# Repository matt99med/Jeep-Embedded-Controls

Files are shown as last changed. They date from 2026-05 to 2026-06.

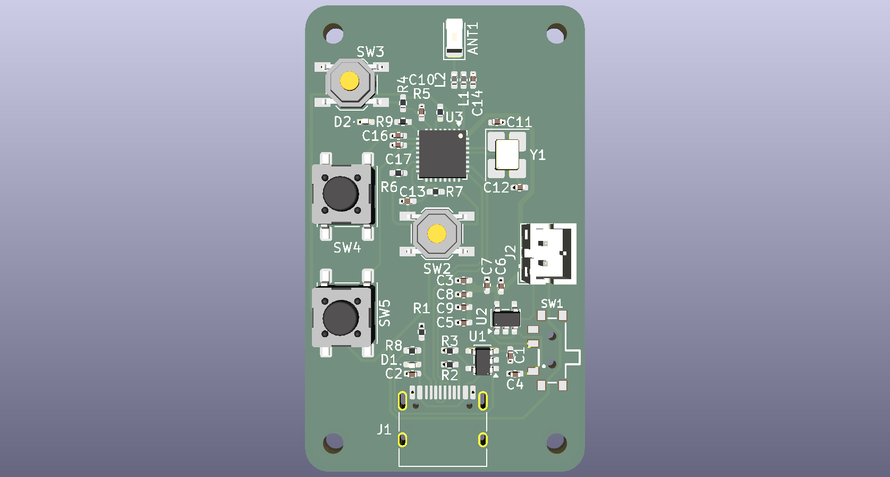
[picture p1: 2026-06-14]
images/JeepKeyfob_3D_Top.png

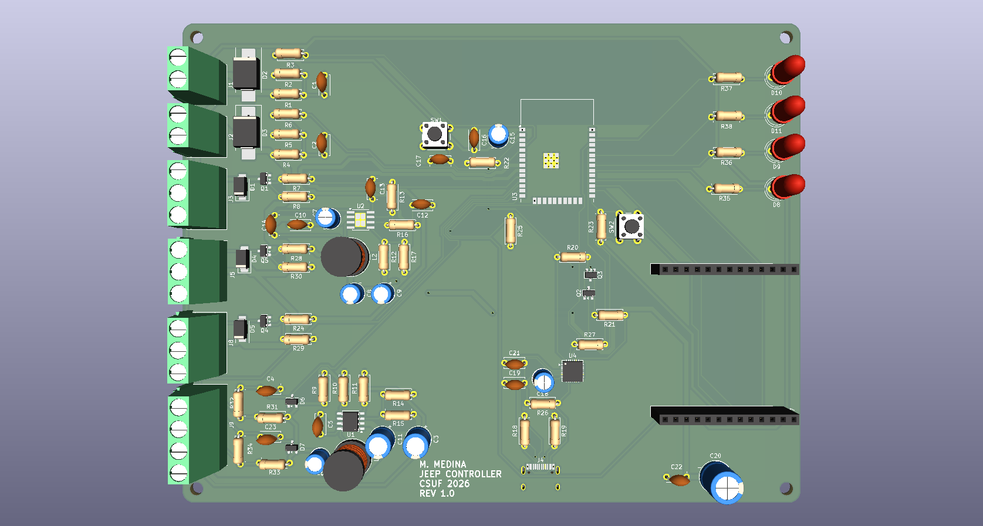
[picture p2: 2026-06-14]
images/JeepController_3D_Top.png

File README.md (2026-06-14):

# Jeep Embedded Controls

A custom embedded security and control system for a 1995 Jeep Wrangler, built as a
personal project to demonstrate full-stack embedded systems development across firmware,
hardware, PCB design, power electronics, and mobile applications.

## Project Overview

This system provides remote control, alarm/immobilization, and real-time GPS tracking
for a 1995 Jeep Wrangler using two custom-designed PCBs, 3D printed enclosures, and a
companion web app. A keyfob and a main controller communicate wirelessly via ESP-NOW,
with 4G LTE cellular for remote GPS tracking accessible from any device.

The system is designed around a **battery-backed, low-power security architecture**: the
controller runs from its own auxiliary battery so it keeps tracking and alarming even if
the vehicle's main battery is disconnected — the exact scenario a theft involves — while
never drawing the vehicle battery down when parked.

## Demo

> Live GPS tracker web app: [Jeep Tracker](https://matt99med.github.io/Jeep-Embedded-Controls/)

## Features

- Remote kill switch (immobilizer) via custom ESP-NOW keyfob
- **Hidden manual bypass switch** — fail-safe so a controller fault never strands the vehicle
- Hood and shock sensor triggered siren with automatic arming
- Remote arm/disarm via keyfob with LED status feedback
- Real-time GPS tracking via 4G LTE cellular (SIM7600G-H)
- Web app for live location tracking via MQTT over HiveMQ Cloud
- **Auxiliary backup battery** — system survives main-battery disconnect
- **Vehicle-sensing charge control** — aux battery charges only while the alternator runs,
  so the vehicle battery is never drained while parked (months of standby)
- **Deep-sleep architecture** — wakes on hood/shock/timer events; tens of µA when parked
- Hardware low-voltage disconnect protecting the aux battery from over-discharge
- LiPo battery powered keyfob with USB-C charging

## Hardware

### Main Controller

- **ESP32-WROOM-32E** module (240MHz dual-core, Wi-Fi, BT)
- **CP2102N** USB-to-UART bridge with auto-reset programming circuit (USB-C)
- **SIM7600G-H** 4G LTE + GPS (Waveshare breakout, socketed)
- **Auxiliary battery system:** 12V sealed AGM battery
- **Vehicle-sensing charge relay:** connects vehicle 12V to aux battery only when the
  alternator is running (firmware-controlled, AO3400A driver, off-board relay)
- **Power rails:**
  - LM5164-Q1 wide-Vin synchronous buck (battery -> 3.3V, ~10uA quiescent)
  - MP2307DN buck (battery -> 3.8V for SIM7600, gated by GPIO for sleep)
  - Hardware UVLO low-voltage disconnect on the 3.3V buck
- Relay/fuse box for kill switch + siren (off-board high current)
- BAT54S input clamps + RC filtering on hood/shock sensor inputs
- SMCJ33A TVS protection on 12V inputs
- 4 firmware-controlled status LEDs (system / cellular / armed / fault)
- Custom 2-layer KiCad PCB, 154.5 x 120 mm
- Custom Fusion 360 enclosure (in progress)

### Keyfob

- **ESP32-C3FH4X** (bare QFN32, 160MHz RISC-V, in-package 4MB flash)
- **Johanson 2450AT18A100E-AEC** chip antenna with L-C-L matching network
- 40MHz crystal (NX3225GD-40M)
- MCP73831 LiPo charger IC
- 3.7V LiPo battery
- USB-C charging + native USB programming (GPIO18/19)
- AP2112K-3.3 LDO
- Tactile buttons: Lock, Unlock + BOOT/RESET
- Status LEDs: charge + connection
- Slide power switch
- Custom 2-layer KiCad PCB, 30 x 50 mm
- Custom Fusion 360 enclosure (in progress)

## Tech Stack

| Category | Technology |
| --- | --- |
| Firmware | ESP-IDF v6.0 (C) |
| RTOS | FreeRTOS |
| Wireless | ESP-NOW (keyfob <-> controller) |
| Cellular | SIM7600G-H AT commands over UART2 |
| IoT Protocol | MQTT over TLS (HiveMQ Cloud) |
| PCB Design | KiCad 10.0 |
| 3D Modeling | Autodesk Fusion 360 |
| Web App | HTML/CSS/JavaScript + Google Maps API |
| Version Control | Git/GitHub |
| PCB Fabrication | JLCPCB (assembled) |

## System Architecture

```
[Keyfob ESP32-C3] <--ESP-NOW 2.4GHz--> [Main ESP32 Controller]
[Lock/Unlock]                            [Kill Switch / Siren]
                                         [Hood + Shock Sensors]
                                         [Aux Battery + Charge Control]
                                         [Hidden Bypass Switch]
                                                 |
                                         [SIM7600G-H Module]
                                                 |
                                      [Hologram IoT SIM / 4G LTE]
                                                 |
                                        [HiveMQ MQTT Broker]
                                                 |
                                     [Web App / iPhone / Any Device]
```

## Power Architecture

```
[Vehicle 12V] --fused--> [Charge Relay] --(only when alternator running)--> [Aux 12V Battery]
                              ^                                                    |
                       [GPIO sense/control]                                        |
                                                                                   v
                                                          +------------------------+
                                                          |                        |
                                                  [LM5164 Buck]            [MP2307 Buck]
                                                   3.3V (always-on,         3.8V (gated,
                                                   UVLO protected)          SIM7600)
                                                          |                        |
                                                  [ESP32 + logic]          [SIM7600G-H]
```

Key property: when parked, the vehicle battery and the aux battery are physically
disconnected. The controller draws only from the aux battery, so the vehicle always
starts no matter how long it sits.

## Firmware Architecture

The main controller firmware is built around a **tiered low-power state machine** rather
than always-on tasks, to achieve months of parked standby on the auxiliary battery.

### Operating Model

- **Deep sleep** is the default parked state — modem off, CPU halted, only RTC wake
  sources armed. Draw is in the tens of uA.
- **Wake sources:** hood sensor (RTC GPIO), shock sensor (RTC GPIO), or a wake timer for
  scheduled MQTT check-ins. The check-in interval shortens automatically when armed.
- **Active window:** after any activity the controller stays in *light sleep* so the
  radio remains listenable, giving near-instant ESP-NOW lock/unlock response. After an
  idle timeout it drops back to deep sleep.
- On every wake the controller reads vehicle + battery voltage, runs charge control, and
  — if armed and triggered — fires the siren, immobilizes, and pushes an alert + GPS
  burst over cellular.

### Kill Relay Logic (fail-safe)

The kill relay is **energized-to-run**: driving the coil HIGH closes the starter circuit
(vehicle can start); LOW immobilizes. A dead controller, dead battery, or cut wire
therefore fails *immobilized*, and the hidden mechanical bypass switch is the recovery
path. The bypass is intentionally not wired to the PCB.

### Charge Control

Firmware closes the charge relay above 13.2 V on the vehicle-sense line (alternator
running) and opens it below 12.8 V, with hysteresis to avoid chatter. The relay coil is
fed from the vehicle side, so charging is physically impossible when the engine is off
regardless of firmware state.

### Source Layout

```
main_controller/main/
├── main.c            # wake-reason dispatch, tiered sleep state machine
├── config.h          # pin map, thresholds, ESP-NOW protocol
├── system_state.h    # shared state + arm/alarm/charge API
├── gpio_handler.c    # ADC sensing, relay control, arm/alarm, charge logic
├── espnow_handler.c  # keyfob command receiver
└── sim7600.c         # modem power sequencing, GPS, MQTT

keyfob/main/
├── main.c            # deep-sleep wake-on-button, send, LED ack, sleep
├── config.h          # pin map + ESP-NOW protocol
├── espnow_keyfob.c   # one-shot ESP-NOW transmit
└── espnow_keyfob.h
```

### ESP-NOW Message Protocol

| Command | Value | Action |
| --- | ----- | --- |
| CMD_LOCK | 0x01  | Arm siren + immobilize (kill LOW)  |
| CMD_UNLOCK  | 0x02  | Disarm + allow run (kill HIGH) |

### MQTT Topics

| Topic | Direction | Payload |
| --- | --- | --- |
| jeep/gps/request | App -> ESP32 | "request" |
| jeep/gps/data | ESP32 -> App | {"lat":xx.xxx,"lon":xx.xxx} |
| jeep/status | ESP32 -> App | "armed" or "disarmed" |
| jeep/alert | ESP32 -> App | power-cut / tamper event |

> Broker credentials and APN are provided via NVS / `idf.py menuconfig`, not committed to
> source.

## PCB Design

### Keyfob PCB

- 2-layer board, 30 x 50 mm
- All 0402 passives, JLCPCB assembled
- Bare ESP32-C3FH4X with Johanson chip antenna + matching network
- GND copper pour on B.Cu with via stitching
- M2 mounting holes
- USB-C edge connector for charging + programming
- **Status: ordered from JLCPCB (assembled) — awaiting delivery**

### Main Controller PCB

- 2-layer board, 154.5 x 120 mm
- Automotive environment rated design
- Bare ESP32-WROOM-32E + CP2102N programming
- Dual switching power supplies (LM5164 + MP2307)
- Aux battery charge management + UVLO
- Screw-terminal field wiring, socketed SIM7600 carrier
- GND copper pour on B.Cu with via stitching
- M3 mounting holes in all 4 corners
- **Status: ordered from JLCPCB (assembled) — awaiting delivery**

## Status

- [x] Hardware redesign complete (KiCad schematics — both boards, bare-chip)
- [x] Battery-backed power architecture with vehicle-sensing charge control
- [x] Firmware rework for deep-sleep / charge-control architecture
- [x] Keyfob PCB ordered (JLCPCB assembled)
- [x] Main controller PCB ordered (JLCPCB assembled)
- [ ] PCB bring-up and board-level testing
- [ ] SIM7600 MQTT/cellular integration (broker connect + report cycle)
- [ ] 3D printed enclosures (Fusion 360 — in progress)
- [ ] Hidden bypass switch installation
- [ ] System integration and testing
- [ ] Final installation in 1995 Jeep Wrangler

## Author

**Matthew Medina**

California State University Fullerton — BS/MS Computer Engineering

GitHub: [matt99med](https://github.com/matt99med)

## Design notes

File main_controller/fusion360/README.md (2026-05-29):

# Fusion 360 Enclosures

3D printed enclosures for the Jeep Controller system.

## Designs in progress
- Main controller engine bay enclosure
- Keyfob enclosure
- Off-road light switch panel (radio delete)

STL files will be added here when designs are complete.

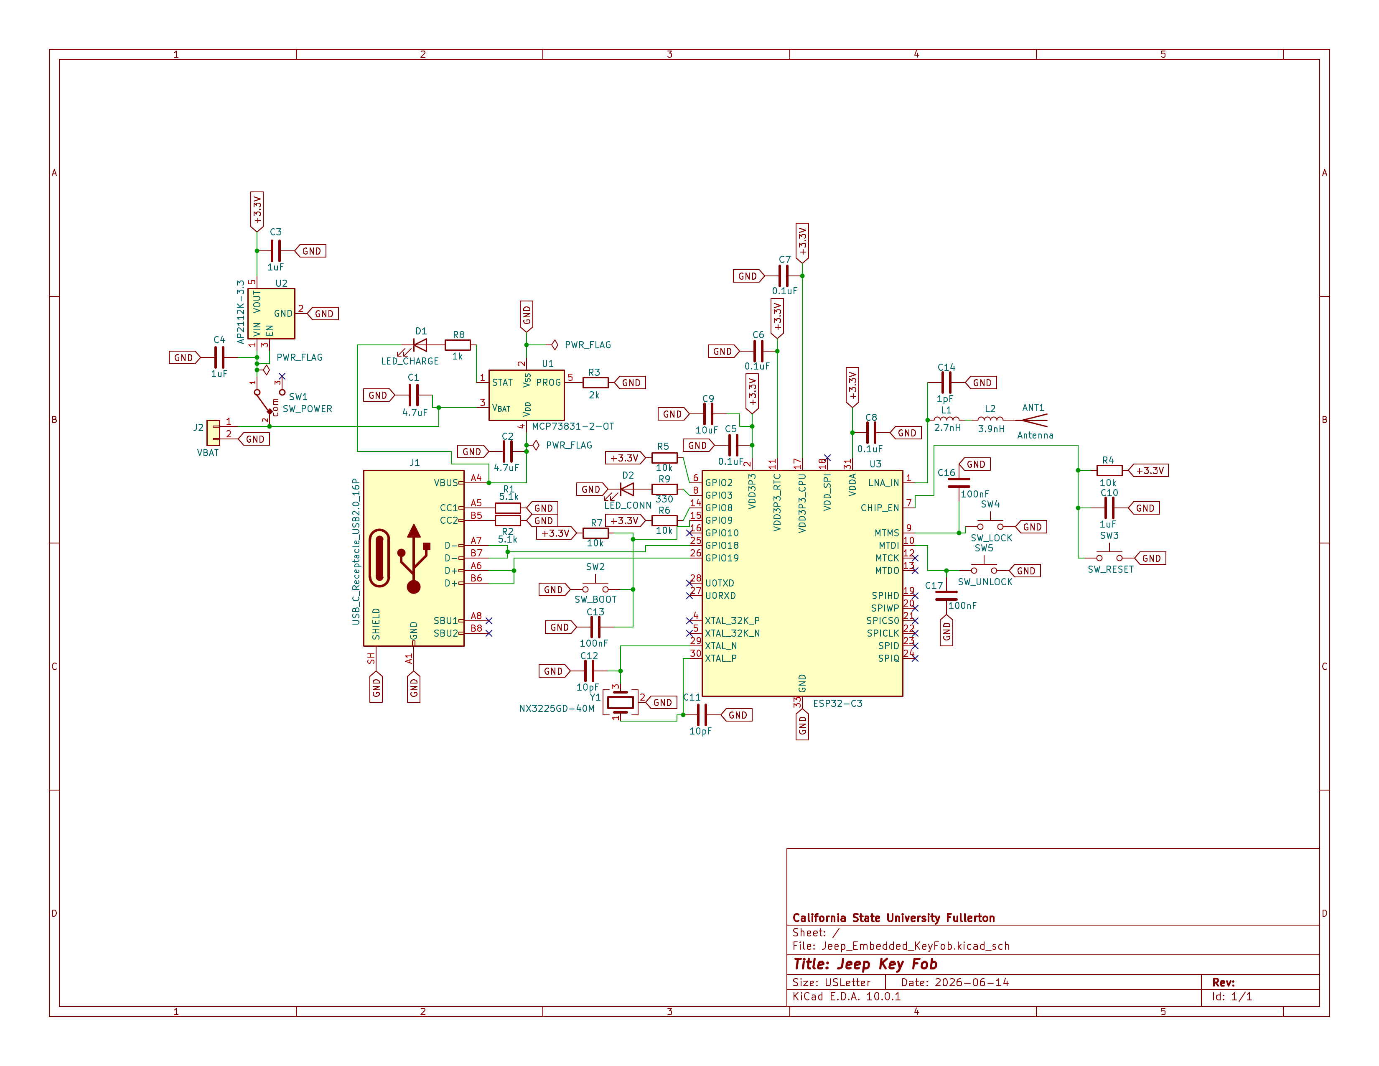
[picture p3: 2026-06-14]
schematics/Jeep_KeyFob.png

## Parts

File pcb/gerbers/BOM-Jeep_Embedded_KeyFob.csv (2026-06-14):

Comment | Designator | Footprint | LCSC | Quantity
0.1uF | C5,C6,C7,C8 | C_0402_1005Metric_Pad0.74x0.62mm_HandSolder | C141382 | 4
100nF | C13,C16,C17 | C_0402_1005Metric_Pad0.74x0.62mm_HandSolder | C1525 | 3
10k | R4,R5,R6,R7 | R_0402_1005Metric_Pad0.72x0.64mm_HandSolder | C11616 | 4
10pF | C11,C12 | C_0402_1005Metric_Pad0.74x0.62mm_HandSolder | C32949 | 2
10uF | C9 | C_0402_1005Metric_Pad0.74x0.62mm_HandSolder | C15525 | 1
1k | R8 | R_0402_1005Metric_Pad0.72x0.64mm_HandSolder | C11702 | 1
1pF | C14 | C_0402_1005Metric_Pad0.74x0.62mm_HandSolder | C1550 | 1
1uF | C10,C3,C4 | C_0402_1005Metric_Pad0.74x0.62mm_HandSolder | C52923 | 3
2.7nH | L1 | L_0402_1005Metric_Pad0.77x0.64mm_HandSolder | C27123 | 1
2k | R3 | R_0402_1005Metric_Pad0.72x0.64mm_HandSolder | C4109 | 1
3.9nH | L2 | L_0402_1005Metric_Pad0.77x0.64mm_HandSolder | C14033 | 1
330 | R9 | R_0402_1005Metric_Pad0.72x0.64mm_HandSolder | C25104 | 1
4.7uF | C1,C2 | C_0402_1005Metric_Pad0.74x0.62mm_HandSolder | C23733 | 2
5.1k | R1,R2 | R_0402_1005Metric_Pad0.72x0.64mm_HandSolder | C25905 | 2
AP2112K-3.3 | U2 | SOT-23-5 | C51118 | 1
Antenna | ANT1 | Johanson_2450AT18x100 | C89334 | 1
ESP32-C3 | U3 | QFN-32-1EP_5x5mm_P0.5mm_EP3.7x3.7mm | C2858491 | 1
LED_CHARGE | D1 | LED_0402_1005Metric_Pad0.77x0.64mm_HandSolder | C71911 | 1
LED_CONN | D2 | LED_0402_1005Metric_Pad0.77x0.64mm_HandSolder | C74338 | 1
MCP73831-2-OT | U1 | SOT-23-5 | C424093 | 1
NX3225GD-40M | Y1 | Crystal_SMD_3225-4Pin_3.2x2.5mm_HandSoldering | C9010 | 1
SW_BOOT | SW2 | SW_SPST_TL3342 | C19779067 | 1
SW_LOCK | SW4 | SW_SPST_PTS645Sx43SMTR92 | C19779067 | 1
SW_POWER | SW1 | 450404015514 | C97433 | 1
SW_RESET | SW3 | SW_SPST_TL3342 | C19779067 | 1
SW_UNLOCK | SW5 | SW_SPST_PTS645Sx43SMTR92 | C19779067 | 1
USB_C_Receptacle_USB2.0_16P | J1 | USB_C_Receptacle_HRO_TYPE-C-31-M-12 | C393939 | 1
VBAT | J2 | JST_PH_B2B-PH-K_1x02_P2.00mm_Vertical | C131337 | 1

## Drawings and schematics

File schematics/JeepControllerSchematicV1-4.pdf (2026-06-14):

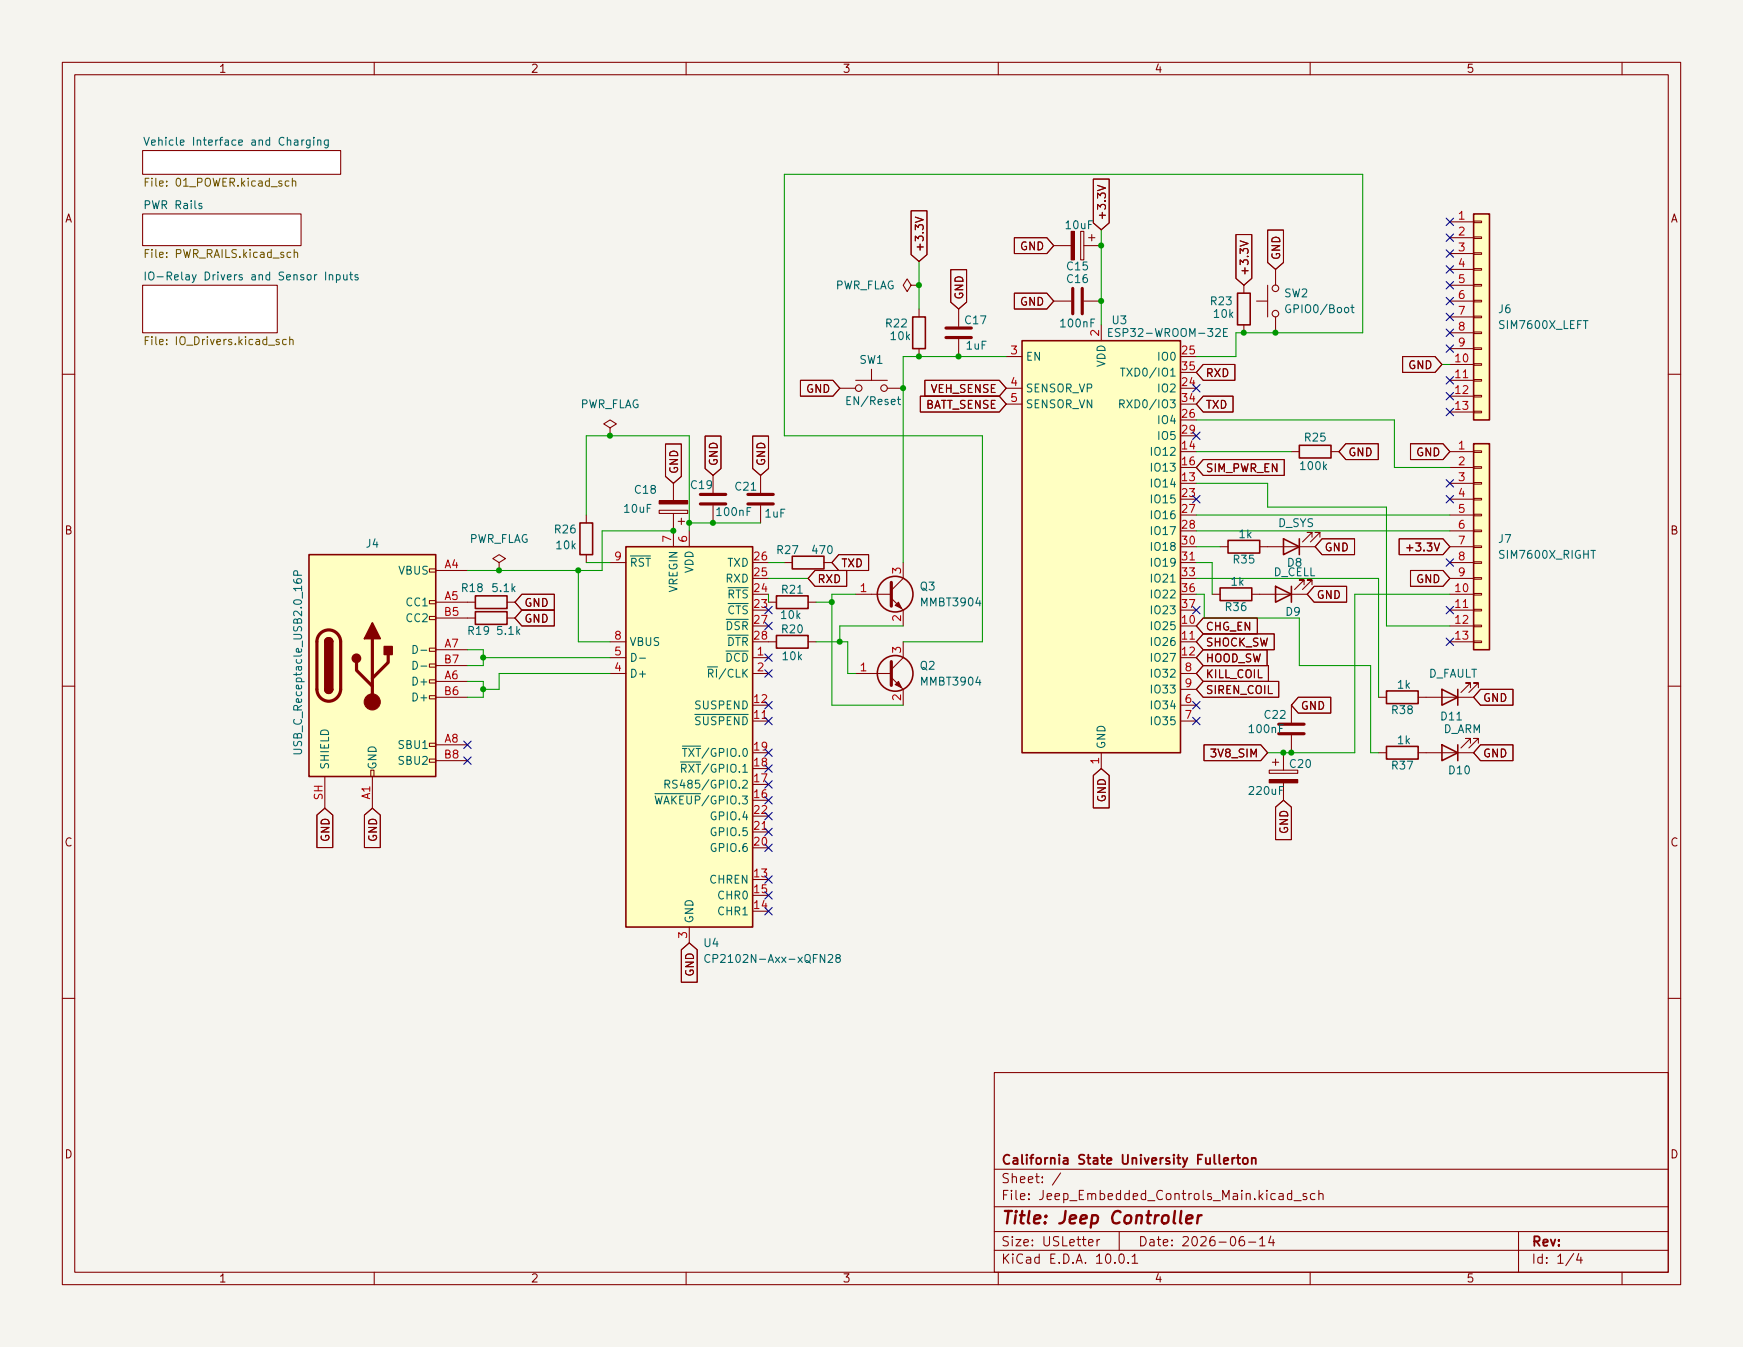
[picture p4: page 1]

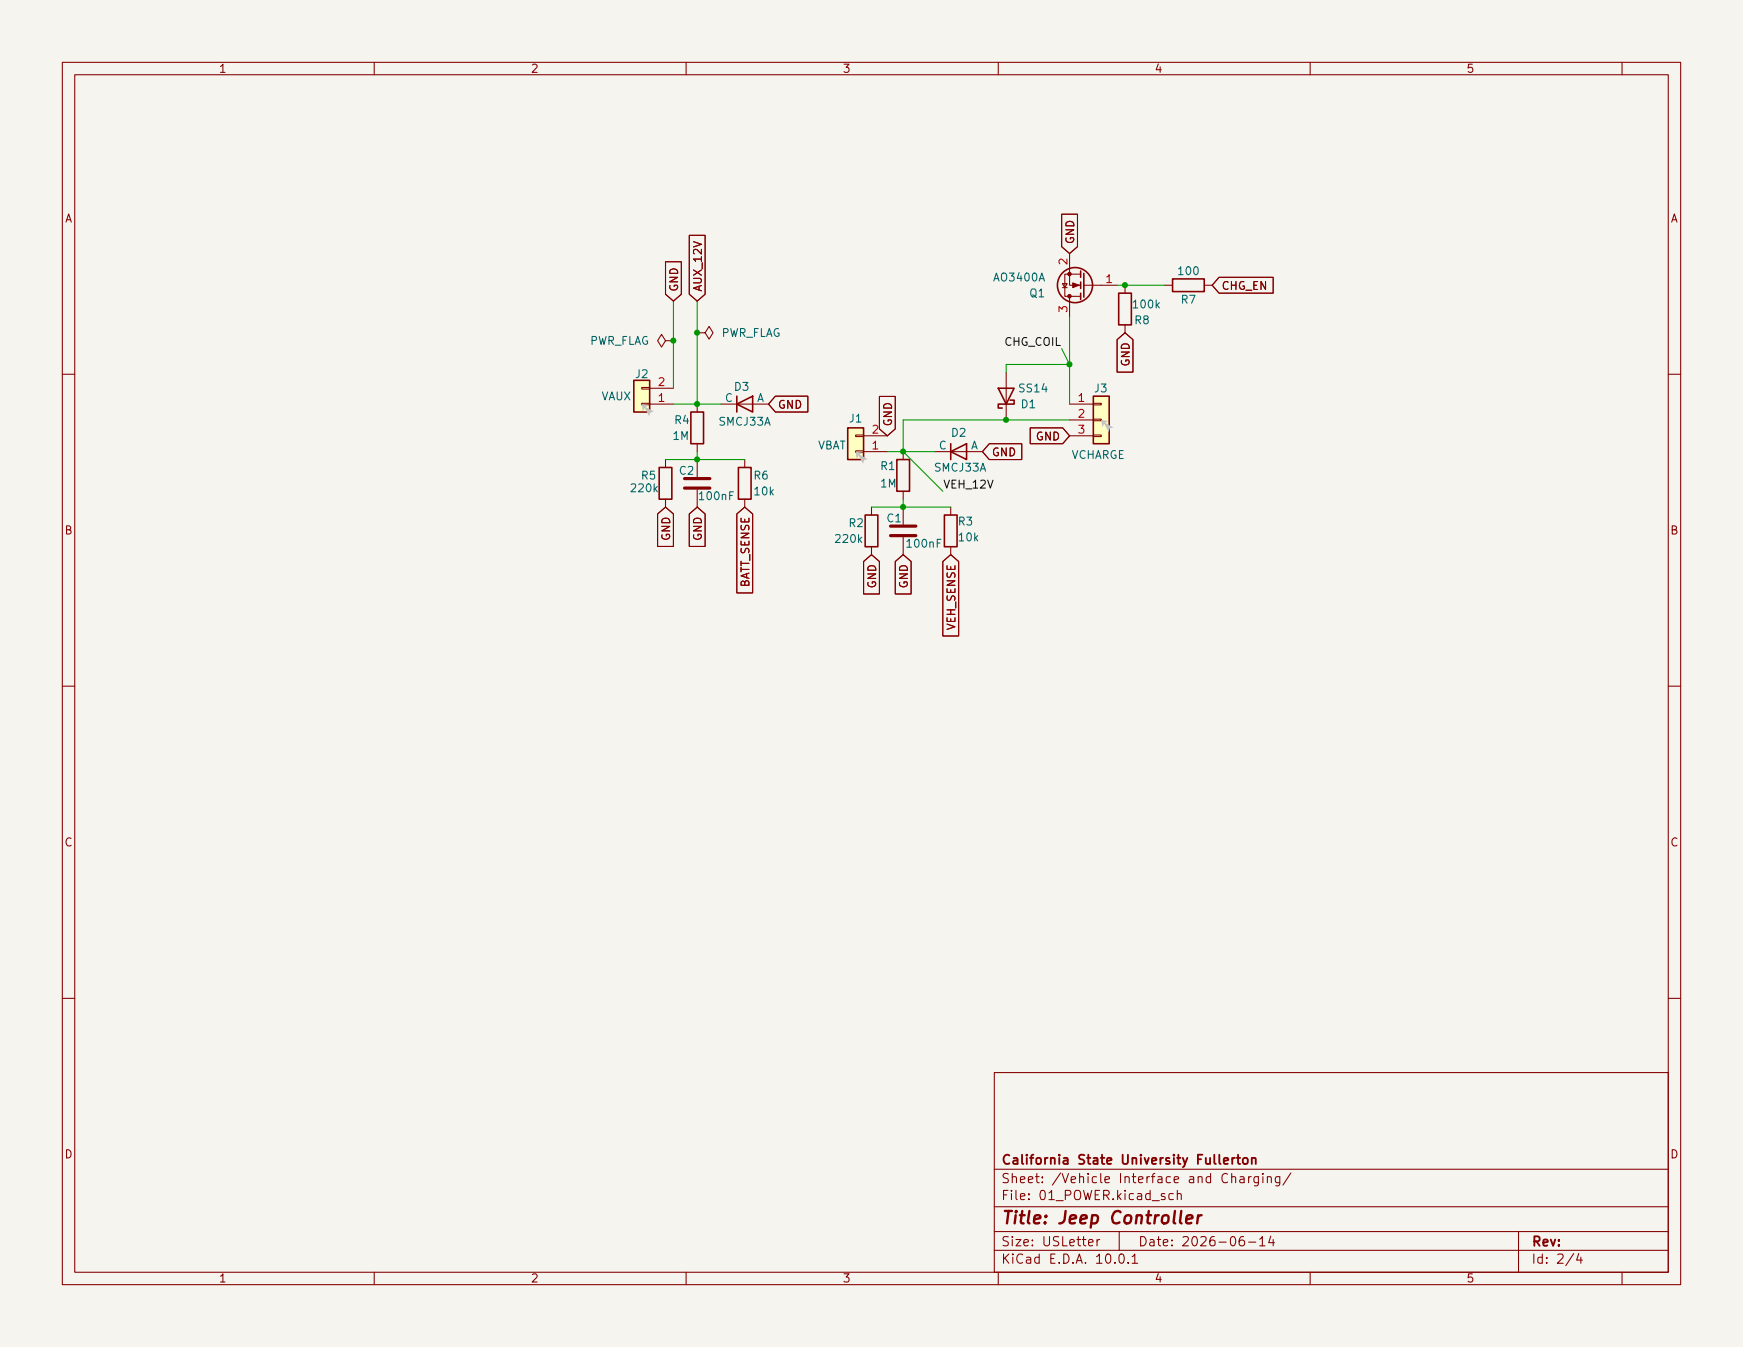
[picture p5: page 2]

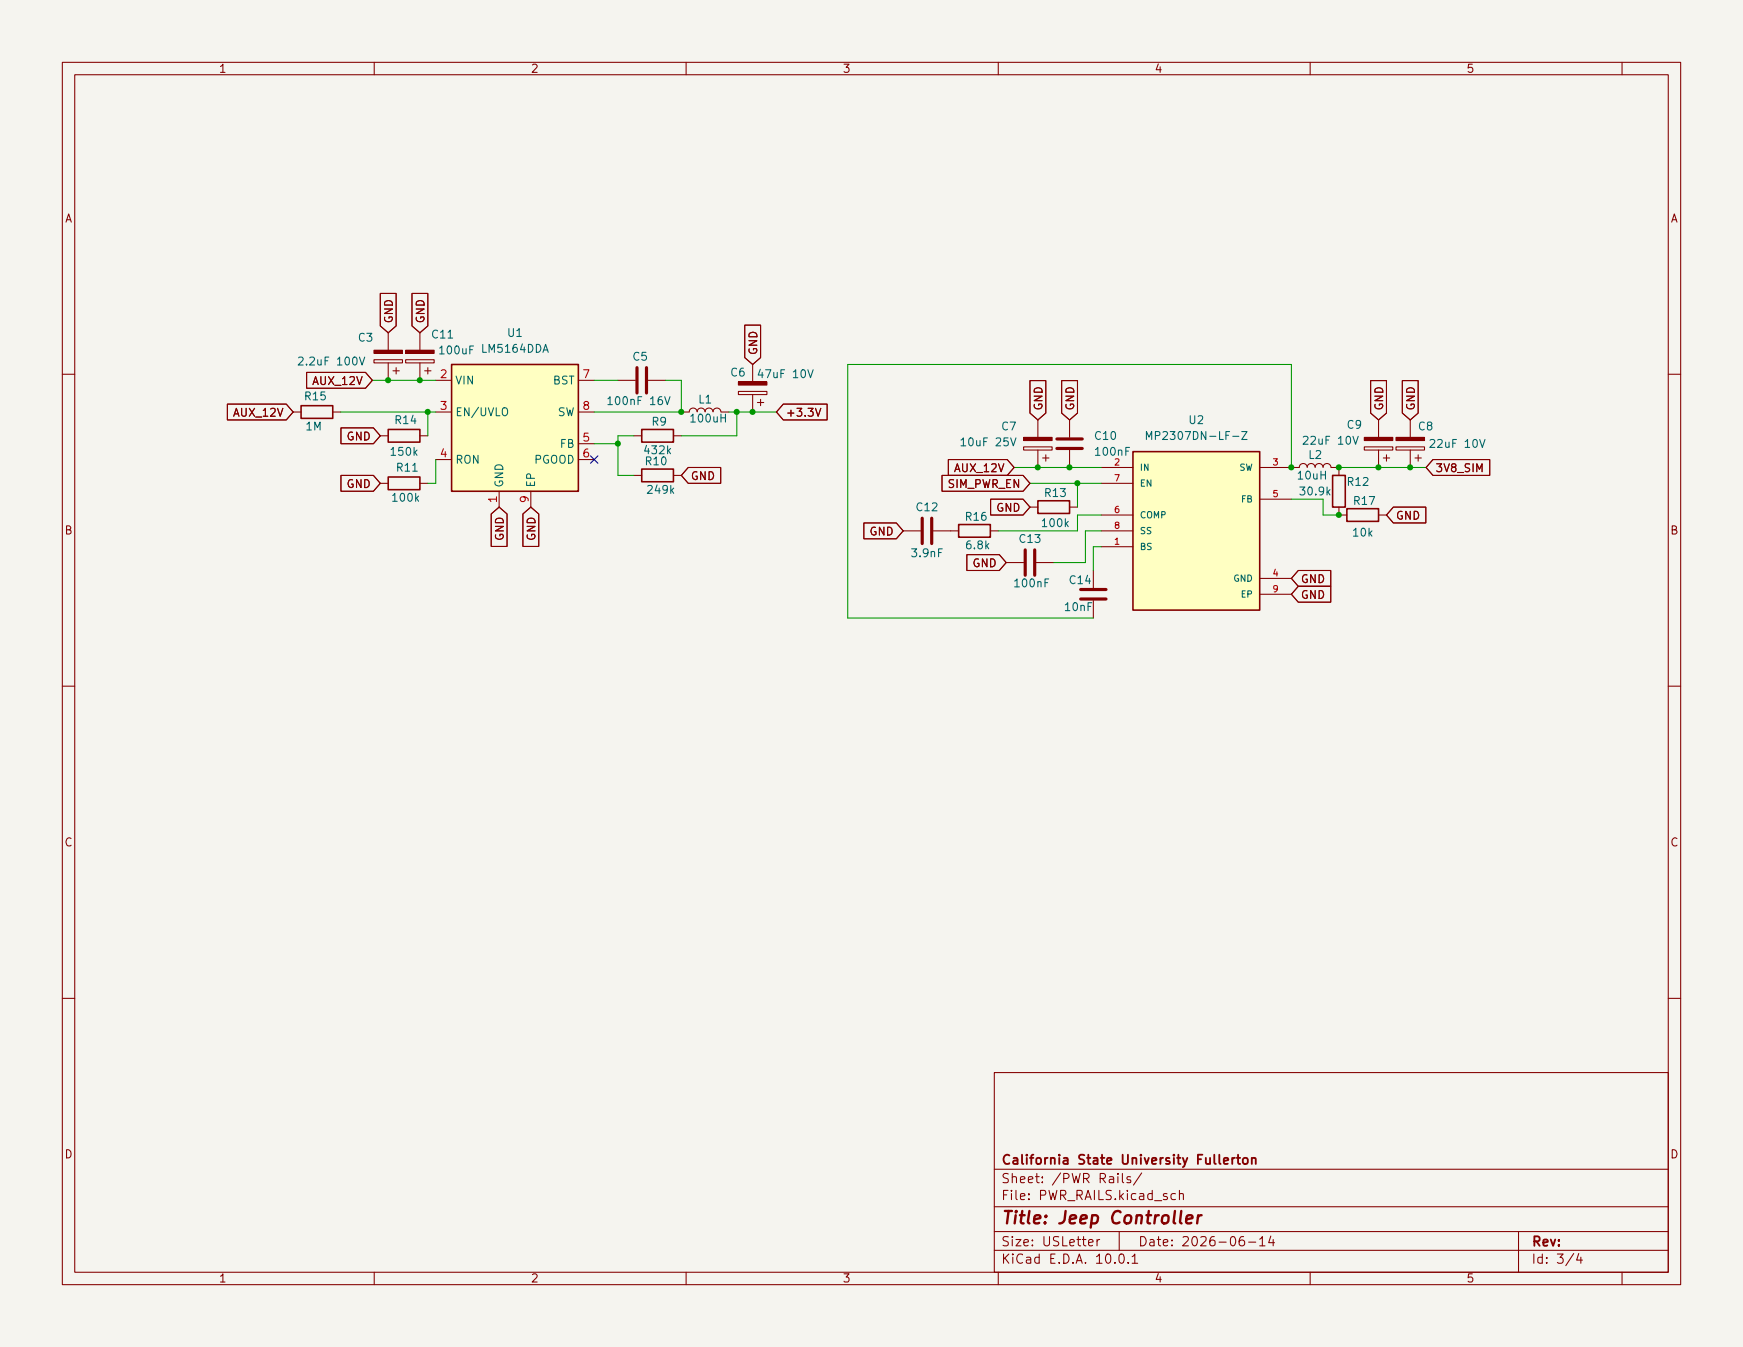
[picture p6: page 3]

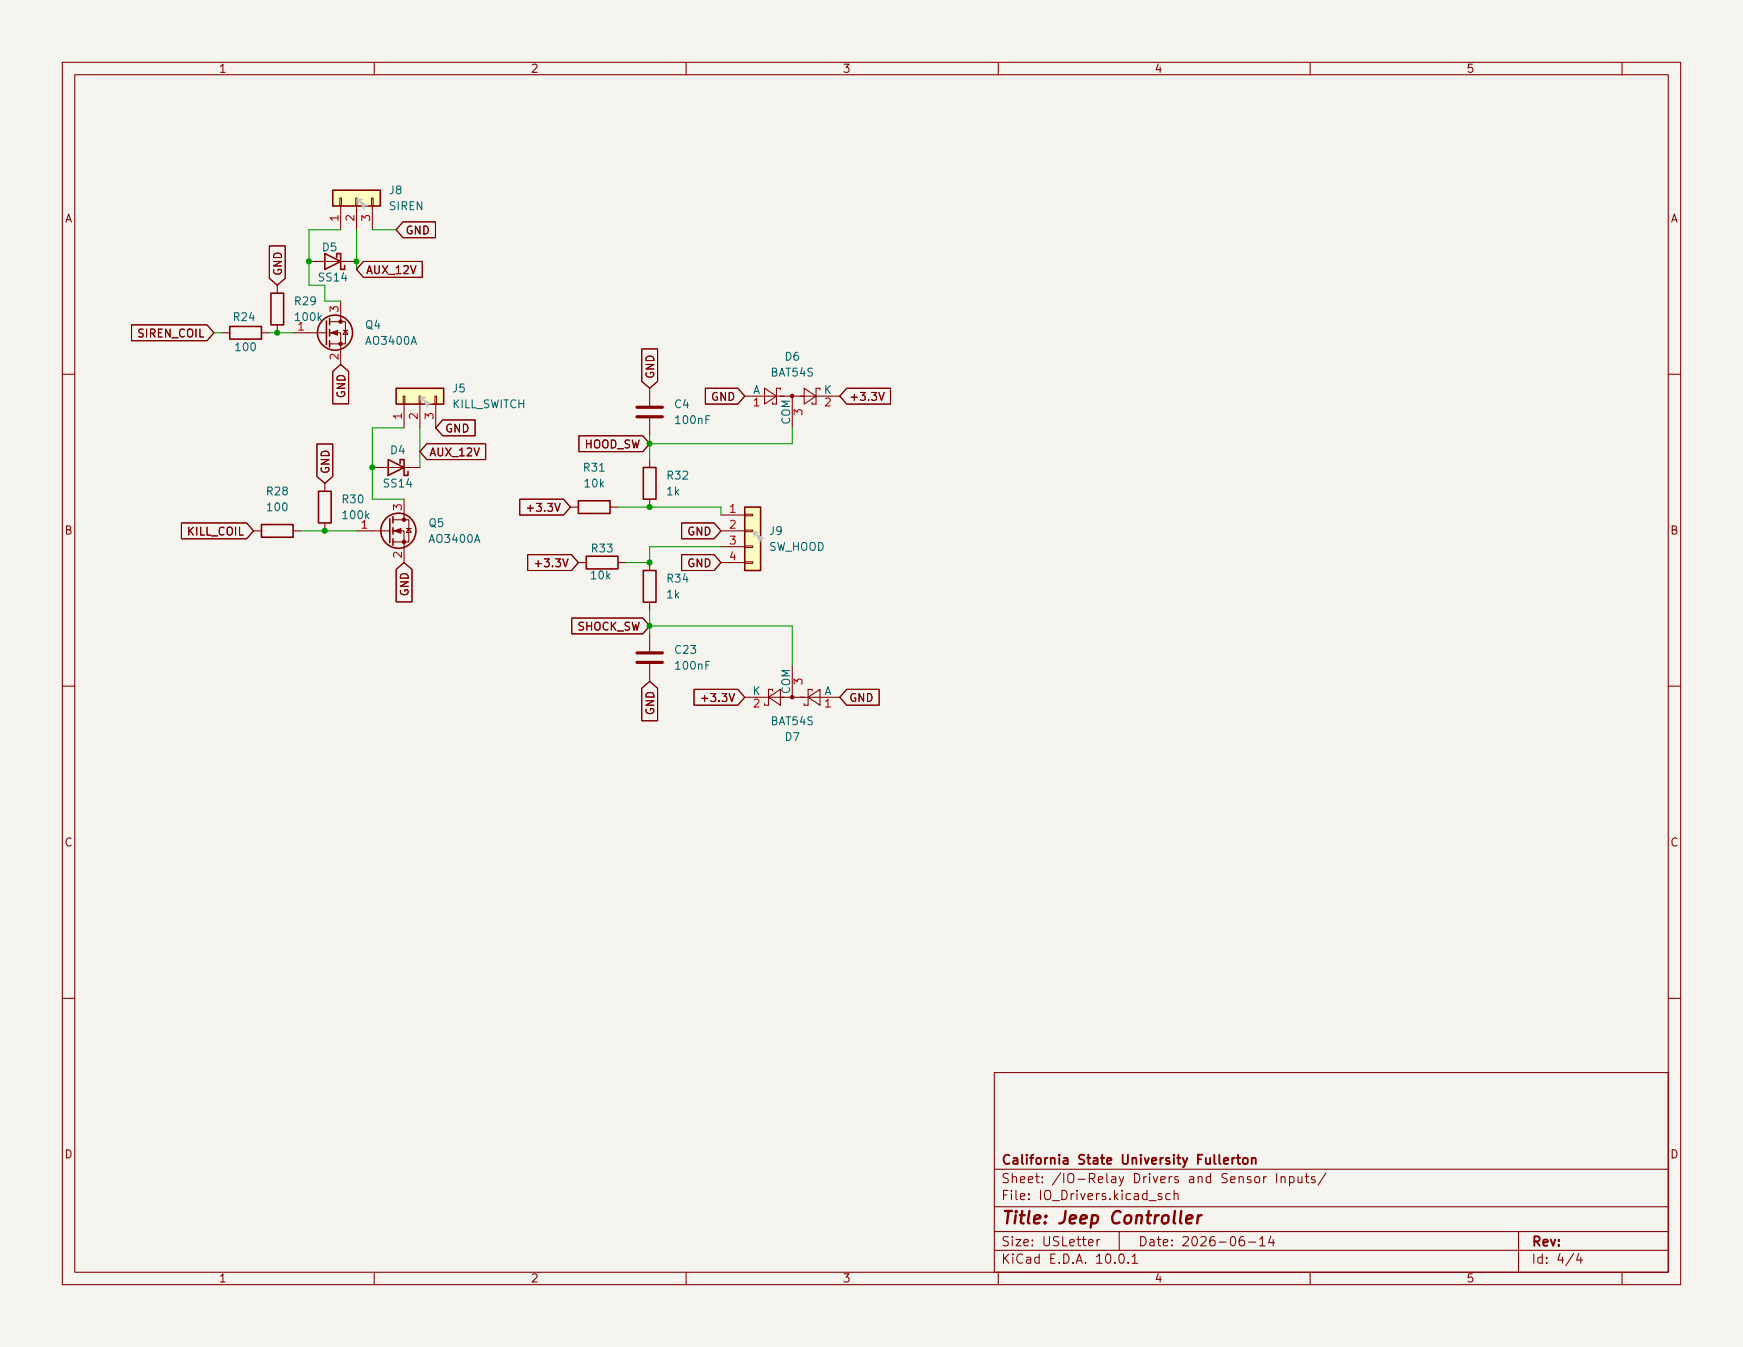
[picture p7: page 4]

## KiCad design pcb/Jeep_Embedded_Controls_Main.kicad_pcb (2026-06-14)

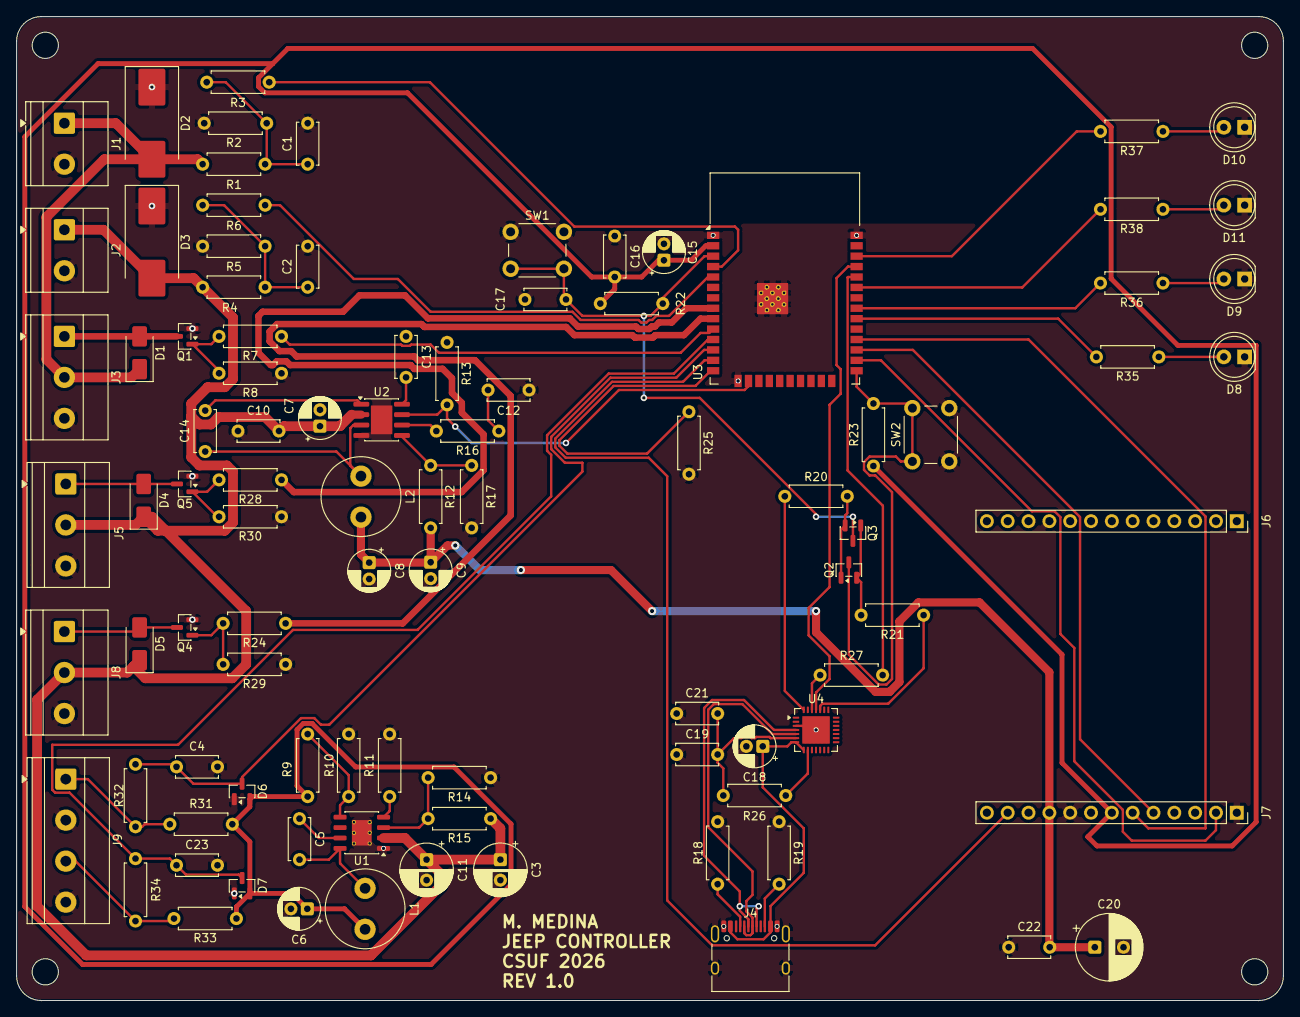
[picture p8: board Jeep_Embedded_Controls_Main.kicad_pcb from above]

Board: 2 copper layers, 154.5 x 120.0 mm, 94 parts (0 on the bottom side), 63 nets.

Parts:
C1, C2, C4, C10, C13, C16, C19, C22, C23: 100nF; C_Disc_D5.0mm_W2.5mm_P5.00mm
C3: 2.2uF 100V; CP_Radial_D6.3mm_P2.50mm
C5: 100nF 16V; C_Disc_D5.0mm_W2.5mm_P5.00mm
C6: 47uF 10V; CP_Radial_D5.0mm_P2.00mm
C7: 10uF 25V; CP_Radial_D5.0mm_P2.00mm
C8, C9: 22uF 10V; CP_Radial_D5.0mm_P2.00mm
C11: 100uF; CP_Radial_D6.3mm_P2.50mm
C12: 3.9nF; C_Disc_D5.0mm_W2.5mm_P5.00mm
C14: 10nF; C_Disc_D5.0mm_W2.5mm_P5.00mm
C15, C18: 10uF; CP_Radial_D5.0mm_P2.00mm
C17, C21: 1uF; C_Disc_D5.0mm_W2.5mm_P5.00mm
C20: 220uF; CP_Radial_D8.0mm_P3.50mm
D1, D4, D5: SS14; D_SMA
D2, D3: SMCJ33A; D_SMC_Handsoldering
D6, D7: BAT54S; SOT-23
D8: D_SYS; LED_D5.0mm
D9: D_CELL; LED_D5.0mm
D10: D_ARM; LED_D5.0mm
D11: D_FAULT; LED_D5.0mm
J1: VBAT; TerminalBlock_Phoenix_MKDS-1,5-2_1x02_P5.00mm_Horizontal
J2: VAUX; TerminalBlock_Phoenix_MKDS-1,5-2_1x02_P5.00mm_Horizontal
J3: VCHARGE; TerminalBlock_Phoenix_MKDS-1,5-3_1x03_P5.00mm_Horizontal
J4: USB_C_Receptacle_USB2.0_16P; USB_C_Receptacle_HRO_TYPE-C-31-M-12
J5: KILL_SWITCH; TerminalBlock_Phoenix_MKDS-1,5-3_1x03_P5.00mm_Horizontal
J6: SIM7600X_LEFT; PinSocket_1x13_P2.54mm_Vertical
J7: SIM7600X_RIGHT; PinSocket_1x13_P2.54mm_Vertical
J8: SIREN; TerminalBlock_Phoenix_MKDS-1,5-3_1x03_P5.00mm_Horizontal
J9: SW_HOOD; TerminalBlock_Phoenix_MKDS-1,5-4_1x04_P5.00mm_Horizontal
L1: 100uH; L_Radial_D9.5mm_P5.00mm_Fastron_07HVP
L2: 10uH; L_Radial_D9.5mm_P5.00mm_Fastron_07HVP
Q1, Q4, Q5: AO3400A; SOT-23
Q2, Q3: MMBT3904; SOT-23
R1, R4, R15: 1M; R_Axial_DIN0207_L6.3mm_D2.5mm_P7.62mm_Horizontal
R2, R5: 220k; R_Axial_DIN0207_L6.3mm_D2.5mm_P7.62mm_Horizontal
R3, R6, R17, R20, R21, R22, R23, R26, R31, R33: 10k; R_Axial_DIN0207_L6.3mm_D2.5mm_P7.62mm_Horizontal
R7, R24, R28: 100; R_Axial_DIN0207_L6.3mm_D2.5mm_P7.62mm_Horizontal
R8, R11, R13, R25, R29, R30: 100k; R_Axial_DIN0207_L6.3mm_D2.5mm_P7.62mm_Horizontal
R9: 432k; R_Axial_DIN0207_L6.3mm_D2.5mm_P7.62mm_Horizontal
R10: 249k; R_Axial_DIN0207_L6.3mm_D2.5mm_P7.62mm_Horizontal
R12: 30.9k; R_Axial_DIN0207_L6.3mm_D2.5mm_P7.62mm_Horizontal
R14: 150k; R_Axial_DIN0207_L6.3mm_D2.5mm_P7.62mm_Horizontal
R16: 6.8k; R_Axial_DIN0207_L6.3mm_D2.5mm_P7.62mm_Horizontal
R18, R19: 5.1k; R_Axial_DIN0207_L6.3mm_D2.5mm_P7.62mm_Horizontal
R27: 470; R_Axial_DIN0207_L6.3mm_D2.5mm_P7.62mm_Horizontal
R32, R34, R35, R36, R37, R38: 1k; R_Axial_DIN0207_L6.3mm_D2.5mm_P7.62mm_Horizontal
SW1: EN/Reset; SW_PUSH_6mm
SW2: GPIO0/Boot; SW_PUSH_6mm
U1: LM5164DDA; HSOP-8-1EP_3.9x4.9mm_P1.27mm_EP2.41x3.1mm_ThermalVias
U2: MP2307DN-LF-Z; SOIC-8-1EP_3.9x4.9mm_P1.27mm_EP2.62x3.51mm
U3: ESP32-WROOM-32E; ESP32-WROOM-32D
U4: CP2102N-Axx-xQFN28; QFN-28-1EP_5x5mm_P0.5mm_EP3.35x3.35mm

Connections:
3V8_SIM: C8.1, C9.1, C20.1, C22.2, J7.10, L2.2, R12.2
+3.3V: C6.1, C15.1, C16.2, D6.2 (K), D7.2 (K), J7.7, L1.2, R9.2, R22.1, R23.1, R31.1, R33.1, U3.2 (VDD)
/Vehicle Interface and Charging/CHG_COIL: D1.2 (A), J3.1, Q1.3 (D)
/Vehicle Interface and Charging/VEH_12V: D1.1 (K), D2.2 (C), J1.1, J3.2, R1.1
AUX_12V: C3.1, C7.1, C10.2, C11.1, D3.2 (C), D4.1 (K), D5.1 (K), J2.1, J5.2, J8.2, R4.1, R15.1, U1.2 (VIN), U2.2 (IN)
BATT_SENSE: R6.2, U3.5 (SENSOR_VN)
CHG_EN: R7.1, U3.10 (IO25)
GND: C1.2, C2.2, C3.2, C4.1, C6.2, C7.2, C8.2, C9.2, C10.1, C11.2, C12.1, C13.1, C15.2, C16.1, C17.1, C18.2, C19.1, C20.2, C21.1, C22.1, C23.2, D2.1 (A), D3.1 (A), D6.1 (A), D7.1 (A), D8.1 (K), D9.1 (K), D10.1 (K), D11.1 (K), J1.2, J2.2, J3.3, J4.A1 (GND), J4.A12 (GND), J4.B1 (GND), J4.B12 (GND), J4.SH (SHIELD), J5.3, J6.10 (Pin_10_10), J7.1, J7.9, J8.3, J9.2, J9.4, Q1.2 (S), Q4.2 (S), Q5.2 (S), R2.2, R5.2, R8.1, R10.2, R11.1, R13.1, R14.1, R17.2, R18.2, R19.1, R25.2, R29.1, R30.1, SW1.1, SW2.2, U1.1 (GND), U1.9 (EP), U2.4 (GND), U2.9 (EP), U3.1 (GND), U3.15 (GND), U3.38 (GND), U3.39 (GND), U4.3 (GND), U4.29 (GND)
HOOD_SW: C4.2, D6.3 (COM), R32.1, U3.12 (IO27)
KILL_COIL: R28.1, U3.8 (IO32)
unnamed: C1.1, R1.2, R2.1, R3.1
unnamed: C2.1, R4.2, R5.1, R6.1
unnamed: C12.2, R16.1
unnamed: D4.2 (A), J5.1, Q5.3 (D)
unnamed: D5.2 (A), J8.1, Q4.3 (D)
unnamed: D8.2 (A), R35.1
unnamed: D9.2 (A), R36.1
unnamed: D10.2 (A), R37.1
unnamed: D11.2 (A), R38.1
unnamed: J4.A5 (CC1), R18.1
unnamed: J4.B5 (CC2), R19.2
unnamed: J7.2, U3.26 (IO4)
unnamed: J7.5, U3.27 (IO16)
unnamed: J7.6, U3.28 (IO17)
unnamed: J7.12, U3.13 (IO14)
unnamed: J9.1, R31.2, R32.2
unnamed: J9.3, R33.2, R34.1
unnamed: Q1.1 (G), R7.2, R8.2
unnamed: Q2.1 (B), Q3.2 (E), R20.2
unnamed: Q2.3 (C), R23.2, SW2.1, U3.25 (IO0)
unnamed: Q2.2 (E), Q3.1 (B), R21.2
unnamed: C17.2, Q3.3 (C), R22.2, SW1.2, U3.3 (EN)
unnamed: Q4.1 (G), R24.2, R29.2
unnamed: Q5.1 (G), R28.2, R30.2
unnamed: C5.1, U1.7 (BST)
unnamed: R14.2, R15.2, U1.3 (EN/UVLO)
unnamed: R9.1, R10.1, U1.5 (FB)
unnamed: R11.2, U1.4 (RON)
unnamed: C5.2, L1.1, U1.8 (SW)
unnamed: C14.2, U2.1 (BS)
unnamed: R16.2, U2.6 (COMP)
unnamed: R12.1, R17.1, U2.5 (FB)
unnamed: C13.2, U2.8 (SS)
unnamed: C14.1, L2.1, U2.3 (SW)
unnamed: R25.1, U3.14 (IO12)
unnamed: R35.2, U3.30 (IO18)
unnamed: R36.2, U3.31 (IO19)
unnamed: R38.2, U3.33 (IO21)
unnamed: R37.2, U3.36 (IO22)
unnamed: J4.A6 (D+), J4.B6 (D+), U4.4 (D+)
unnamed: J4.A7 (D-), J4.B7 (D-), U4.5 (D-)
unnamed: R27.1, U4.26 (TXD)
unnamed: C18.1, J4.A4 (VBUS), J4.A9 (VBUS), J4.B4 (VBUS), J4.B9 (VBUS), U4.7 (VREGIN), U4.8 (VBUS)
unnamed: C19.2, C21.2, R26.1, U4.6 (VDD)
unnamed: R20.1, U4.28 (~DTR)
unnamed: R26.2, U4.9 (~RST)
unnamed: R21.1, U4.24 (~RTS)
RXD: U3.35 (TXD0/IO1), U4.25 (RXD)
SHOCK_SW: C23.1, D7.3 (COM), R34.2, U3.11 (IO26)
SIM_PWR_EN: R13.2, U2.7 (EN), U3.16 (IO13)
SIREN_COIL: R24.1, U3.9 (IO33)
TXD: R27.2, U3.34 (RXD0/IO3)
VEH_SENSE: R3.2, U3.4 (SENSOR_VP)

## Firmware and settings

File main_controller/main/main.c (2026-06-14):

/*
 * main.c - Jeep Main Controller orchestration
 *
 * Power model (confirmed):
 *   - Runs entirely from the aux AGM battery.
 *   - Default parked state = light sleep while recently active (radio
 *     listenable for instant ESP-NOW lock/unlock), dropping to deep sleep
 *     after ACTIVE_WINDOW_MS of no activity.
 *   - Wakes from deep sleep on: hood (IO27), shock (IO26), or timer
 *     (scheduled MQTT check-in / charge poll).
 *   - On any wake: read sensors + battery + vehicle voltage, run charge
 *     control, and if armed+triggered -> alarm + alert + GPS burst.
 *
 * Wake-on-keyfob caveat: a deep-sleeping ESP32 cannot hear ESP-NOW. The
 * tiered model keeps the radio alive during the active window so fob
 * presses are instant right after any activity; during long deep-sleep
 * stretches the fob is serviced at the next timer wake. For a security
 * fob this is the right tradeoff between instant response and months of
 * battery life.
 */
#include "config.h"
#include "system_state.h"

#include "freertos/FreeRTOS.h"
#include "freertos/task.h"
#include "esp_sleep.h"
#include "esp_wifi.h"
#include "esp_event.h"
#include "esp_log.h"
#include "nvs_flash.h"
#include "driver/rtc_io.h"

static const char *TAG = "main";

/* Global state instance */
system_state_t g_state = {
    .arm_state = STATE_DISARMED,
    .last_seq  = 0xFF,
};

/* from other modules */
void gpio_handler_init(void);
bool gpio_hood_triggered(void);
bool gpio_shock_triggered(void);
void espnow_handler_init(void);
void sim7600_init_uart(void);
bool sim7600_report_cycle(bool is_alert, const char *reason);
void sim7600_power_off(void);

static uint32_t now_ms(void)
{
    return xTaskGetTickCount() * portTICK_PERIOD_MS;
}

/* Configure deep-sleep wake sources: sensors (ext1, low level) + timer. */
static void arm_deep_sleep_wakeups(uint64_t timer_s)
{
    const uint64_t mask = (1ULL << PIN_HOOD_SW) | (1ULL << PIN_SHOCK_SW);
    /* Sensors idle HIGH, trigger LOW -> wake when ANY goes low. */
    esp_sleep_enable_ext1_wakeup(mask, ESP_EXT1_WAKEUP_ALL_LOW);
    if (timer_s) esp_sleep_enable_timer_wakeup(timer_s * 1000000ULL);
}

/* Decide check-in cadence based on arm/battery state. */
static uint64_t checkin_period_s(void)
{
    if (g_state.batt_critical) return 0;                 /* timer off: only sensor wakes */
    if (g_state.arm_state != STATE_DISARMED) return CHECKIN_INTERVAL_ARMED_S;
    return CHECKIN_INTERVAL_S;
}

/* Handle whatever woke us / whatever happened this active window. */
static void service_once(void)
{
    /* Always: refresh analog state, run charge control + battery eval. */
    sys_update_charge_control();
    sys_update_battery_status();

    bool prev_present = g_state.vehicle_present;

    /* Sensor checks (only meaningful when armed). */
    if (g_state.arm_state != STATE_DISARMED) {
        if (gpio_hood_triggered()) {
            sys_trigger_alarm("hood opened");
            sim7600_report_cycle(true, "hood opened");
        } else if (gpio_shock_triggered()) {
            sys_trigger_alarm("impact detected");
            sim7600_report_cycle(true, "impact detected");
        }
    }

    /* Power-cut detection: vehicle sense lost while we thought present. */
    if (prev_present && !g_state.vehicle_present &&
        g_state.arm_state != STATE_DISARMED) {
        sys_trigger_alarm("vehicle power cut");
        sim7600_report_cycle(true, "vehicle power cut");
    }
}

/* Scheduled check-in: bring up modem, publish status + GPS, tear down. */
static void do_checkin(void)
{
    ESP_LOGI(TAG, "scheduled check-in");
    sim7600_report_cycle(false, NULL);
    sim7600_power_off();
}

void app_main(void)
{
    ESP_ERROR_CHECK(nvs_flash_init());
    ESP_ERROR_CHECK(esp_event_loop_create_default());

    /* Wi-Fi/ESP-NOW base (STA, no association). */
    wifi_init_config_t wcfg = WIFI_INIT_CONFIG_DEFAULT();
    ESP_ERROR_CHECK(esp_wifi_init(&wcfg));
    ESP_ERROR_CHECK(esp_wifi_set_mode(WIFI_MODE_STA));
    ESP_ERROR_CHECK(esp_wifi_set_storage(WIFI_STORAGE_RAM));
    ESP_ERROR_CHECK(esp_wifi_start());
    /* Modem-sleep lets the radio idle between beacons during light sleep. */
    esp_wifi_set_ps(WIFI_PS_MIN_MODEM);

    gpio_handler_init();
    sim7600_init_uart();
    espnow_handler_init();

    /* Determine why we woke. */
    esp_sleep_wakeup_cause_t cause = esp_sleep_get_wakeup_cause();
    switch (cause) {
    case ESP_SLEEP_WAKEUP_EXT1:
        ESP_LOGW(TAG, "woke on sensor");
        service_once();
        break;
    case ESP_SLEEP_WAKEUP_TIMER:
        ESP_LOGI(TAG, "woke on timer");
        service_once();
        if (!g_state.batt_critical) do_checkin();
        break;
    default:
        ESP_LOGI(TAG, "cold boot");
        /* On cold boot, default DISARMED -> allow vehicle to run. */
        sys_set_armed(false);
        service_once();
        break;
    }

    /* --- Active window: stay light-sleep-listenable for ESP-NOW --- */
    g_state.last_activity_ms = now_ms();
    gpio_set_level(PIN_LED_SYS, LED_ON);
    vTaskDelay(pdMS_TO_TICKS(50));
    gpio_set_level(PIN_LED_SYS, LED_OFF);

    while (now_ms() - g_state.last_activity_ms < ACTIVE_WINDOW_MS) {
        /* Light sleep: CPU halts, RAM + radio retained, ESP-NOW callback
         * fires on packet RX (which refreshes last_activity_ms). */
        esp_sleep_enable_timer_wakeup(1 * 1000000ULL);  /* 1s tick */
        esp_light_sleep_start();

        /* periodic housekeeping while in the active window */
        sys_update_charge_control();
        if (g_state.arm_state != STATE_DISARMED) {
            if (gpio_hood_triggered())  sys_trigger_alarm("hood opened");
            if (gpio_shock_triggered()) sys_trigger_alarm("impact detected");
        }
    }

    /* --- Drop to deep sleep --- */
    sys_update_battery_status();
    sim7600_power_off();
    uint64_t period = checkin_period_s();
    ESP_LOGI(TAG, "deep sleep; next timer %llus (arm=%d batt=%.2fV)",
             period, g_state.arm_state, g_state.batt_voltage);
    arm_deep_sleep_wakeups(period);
    esp_deep_sleep_start();
    /* never returns */
}

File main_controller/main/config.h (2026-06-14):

/*
 * config.h - Jeep Embedded Controls : Main Controller
 * Central hardware + behavior configuration.
 *
 * Target: ESP32-WROOM-32E  (ESP-IDF v6.x, FreeRTOS)
 *
 * All pin numbers verified against schematic
 * "Jeep_Embedded_Controls_Main" rev "Update".
 *
 * NOTE ON SAFETY-CRITICAL CONSTANTS:
 *   KILL relay is ENERGIZED-TO-RUN. Driving KILL_COIL HIGH energizes the
 *   relay coil and CLOSES the starter circuit (vehicle can start). Driving
 *   it LOW de-energizes -> vehicle immobilized. A dead controller therefore
 *   fails immobilized; the hidden mechanical BYPASS switch is the recovery
 *   path and is intentionally NOT wired to this board.
 */
#pragma once

#include "driver/gpio.h"

/* ------------------------------------------------------------------ */
/* GPIO ASSIGNMENTS  (from schematic)                                  */
/* ------------------------------------------------------------------ */

/* --- Analog sense (ADC1, input-only pins) --- */
#define PIN_VEH_SENSE      GPIO_NUM_36   /* SENSOR_VP - vehicle 12V divider */
#define PIN_BATT_SENSE     GPIO_NUM_39   /* SENSOR_VN - aux battery divider */
#define ADC_CH_VEH         ADC_CHANNEL_0 /* GPIO36 = ADC1_CH0 */
#define ADC_CH_BATT        ADC_CHANNEL_3 /* GPIO39 = ADC1_CH3 */

/* --- Charge control --- */
#define PIN_CHG_EN         GPIO_NUM_25   /* HIGH = close charge relay        */

/* --- SIM7600 (Waveshare carrier) --- */
#define PIN_SIM_PWR_EN     GPIO_NUM_13   /* HIGH = enable MP2307 3.8V rail   */
#define PIN_SIM_PWRKEY     GPIO_NUM_14   /* power-on toggle (see sequence)   */
#define PIN_SIM_DTR        GPIO_NUM_4    /* sleep/wake control (optional)    */
#define PIN_SIM_RX         GPIO_NUM_16   /* ESP RX  <- modem TXD             */
#define PIN_SIM_TX         GPIO_NUM_17   /* ESP TX  -> modem RXD             */
#define SIM_UART_PORT      UART_NUM_2

/* --- Sensor inputs (RTC-capable -> can wake from deep sleep) --- */
#define PIN_HOOD_SW        GPIO_NUM_27   /* idle HIGH, LOW = hood open       */
#define PIN_SHOCK_SW       GPIO_NUM_26   /* idle HIGH, LOW = impact pulse    */

/* --- Relay coil drivers (low-side N-FET; HIGH = energized) --- */
#define PIN_KILL_COIL      GPIO_NUM_32   /* HIGH = RUN-enabled, LOW = killed */
#define PIN_SIREN_COIL     GPIO_NUM_33   /* HIGH = siren on                  */

/* --- Status LEDs (HIGH = on; dark by default to protect sleep budget) --- */
#define PIN_LED_SYS        GPIO_NUM_19
#define PIN_LED_CELL       GPIO_NUM_18
#define PIN_LED_ARM        GPIO_NUM_21
#define PIN_LED_FAULT      GPIO_NUM_22

/* ------------------------------------------------------------------ */
/* LOGIC LEVELS                                                        */
/* ------------------------------------------------------------------ */
#define RELAY_ON           1
#define RELAY_OFF          0
#define KILL_RUN_ENABLED   1   /* energize coil -> car can start         */
#define KILL_IMMOBILIZED   0
#define SENSOR_IDLE        1   /* pulled high                            */
#define SENSOR_TRIGGERED   0   /* switch closed to ground                */
#define LED_ON             1
#define LED_OFF            0

/* ------------------------------------------------------------------ */
/* ADC SCALING  (divider = 220k / (1M + 220k) = 0.1803)                */
/*   Vpin = Vrail * 0.1803 ; Vrail = Vpin / 0.1803                      */
/* ------------------------------------------------------------------ */
#define DIV_RATIO          0.18033f
#define MV_TO_RAIL(mv)     ((float)(mv) / DIV_RATIO / 1000.0f)  /* -> volts */

/* ------------------------------------------------------------------ */
/* CHARGE CONTROL HYSTERESIS  (vehicle-sense, volts)                   */
/* ------------------------------------------------------------------ */
#define CHG_CLOSE_V        13.20f   /* alternator running -> start charge  */
#define CHG_OPEN_V         12.80f   /* engine off -> disconnect            */

/* ------------------------------------------------------------------ */
/* AUX BATTERY THRESHOLDS  (volts)                                     */
/* ------------------------------------------------------------------ */
#define BATT_LOW_V         12.00f   /* stretch reporting interval          */
#define BATT_CRIT_V        11.50f   /* "going dark" alert + deep sleep only*/
/* Hardware UVLO (LM5164 EN divider) cuts the rail ~11.5V regardless.  */

/* ------------------------------------------------------------------ */
/* VEHICLE-POWER-LOSS DETECTION                                        */
/*   Vehicle sense dropping below this while previously present = the  */
/*   main battery was cut. Highest-value theft signal in the system.   */
/* ------------------------------------------------------------------ */
#define VEH_PRESENT_V      6.00f
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

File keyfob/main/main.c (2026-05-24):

#include <stdio.h>
#include "freertos/FreeRTOS.h"
#include "freertos/task.h"
#include "esp_log.h"
#include "button_handler.h"
#include "led_handler.h"
#include "espnow_keyfob.h"

static const char *TAG = "KEYFOB_MAIN";

// ─── Button task ─────────────────────────────────────
static void button_task(void *pvParameters)
{
    // Start disarmed — green LED
    led_show_disarmed();

    while (1) {
        button_event_t event = button_get_event();

        switch (event) {

            case BTN_LOCK:
                ESP_LOGI(TAG, "Sending LOCK command");
                led_show_sending();
                if (espnow_keyfob_send(CMD_LOCK)) {
                    led_show_armed();
                } else {
                    // Flash red fast to show failure
                    for (int i = 0; i < 3; i++) {
                        led_set_red(true);
                        vTaskDelay(pdMS_TO_TICKS(100));
                        led_set_red(false);
                        vTaskDelay(pdMS_TO_TICKS(100));
                    }
                }
                break;

            case BTN_UNLOCK:
                ESP_LOGI(TAG, "Sending UNLOCK command");
                led_show_sending();
                if (espnow_keyfob_send(CMD_UNLOCK)) {
                    led_show_disarmed();
                } else {
                    for (int i = 0; i < 3; i++) {
                        led_set_red(true);
                        vTaskDelay(pdMS_TO_TICKS(100));
                        led_set_red(false);
                        vTaskDelay(pdMS_TO_TICKS(100));
                    }
                }
                break;

            case BTN_PANIC:
                ESP_LOGI(TAG, "Sending PANIC command");
                led_show_panic();
                espnow_keyfob_send(CMD_PANIC);
                break;

            case BTN_NONE:
            default:
                break;
        }

        vTaskDelay(pdMS_TO_TICKS(10));
    }
}

void app_main(void)
{
    ESP_LOGI(TAG, "Jeep Keyfob booting...");

    button_handler_init();
    led_handler_init();
    espnow_keyfob_init();

    xTaskCreate(button_task, "button_task", 4096, NULL, 5, NULL);

    ESP_LOGI(TAG, "Keyfob running");
}

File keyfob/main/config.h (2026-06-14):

/*
 * config.h - Jeep Embedded Controls : Keyfob
 * Target: ESP32-C3FH4X (ESP-IDF v6.x, FreeRTOS)
 *
 * Pins verified against schematic "Jeep_Embedded_KeyFob".
 *
 * Power model: the C3 sits in deep sleep until a button wakes it. LOCK
 * (GPIO4) and UNLOCK (GPIO5) are both in the GPIO0-5 deep-sleep wake
 * range. On wake: send the command via ESP-NOW, blink the status LED for
 * acknowledgement, then return to deep sleep. Average draw is dominated
 * by the AP2112K LDO quiescent (~55uA), giving very long standby on the
 * LiPo.
 */
#pragma once

#include "driver/gpio.h"

/* --- Buttons (active LOW, external behavior: press pulls to GND) --- */
#define PIN_BTN_LOCK    GPIO_NUM_4
#define PIN_BTN_UNLOCK  GPIO_NUM_5

/* --- Status LED (HIGH = on) --- */
#define PIN_LED_STATUS  GPIO_NUM_3
#define LED_ON   1
#define LED_OFF  0

/* Charge LED is hardwired off the MCP73831 STAT pin - not a GPIO. */

/* --- ESP-NOW command protocol (must match main controller) --- */
typedef enum {
    CMD_LOCK   = 0x01,
    CMD_UNLOCK = 0x02,
} jeep_cmd_t;

typedef struct __attribute__((packed)) {
    uint8_t cmd;
    uint8_t seq;
} espnow_msg_t;

/* Main controller's STA MAC - fill in after reading it from the
 * controller's boot log (espnow_handler_init prints it). */
#define CONTROLLER_MAC { 0x00, 0x00, 0x00, 0x00, 0x00, 0x00 }

/* Timing */
#define BTN_DEBOUNCE_MS   30
#define LED_ACK_MS        120
#define TX_RETRY_COUNT    3

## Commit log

2026-05-24 Add gpio_handler - all GPIO pin definitions and control functions
2026-05-24 Add keyfob firmware - buttons, LEDs, and ESP-NOW communication
2026-05-24 Add keyfob PCB layout and Gerber files
    [Jeep_Embedded_KeyFob-B_Cu.gbr, Jeep_Embedded_KeyFob-B_Mask.gbr, Jeep_Embedded_KeyFob-B_Paste.gbr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]
2026-05-24 Organize keyfob gerbers into gerbers subfolder
    [Jeep_Embedded_KeyFob-B_Cu.gbr, Jeep_Embedded_KeyFob-B_Mask.gbr, Jeep_Embedded_KeyFob-B_Paste.gbr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]
2026-05-24 Organize keyfob pcb files
    [Jeep_Embedded_KeyFob.kicad_pcb]
2026-05-24 create an images folder for the 3d view on Kicad
2026-05-29 Add PCB files, updated schematics, and project images
    [Jeep_Embedded_Controls_Main-B_Cu.gbr, Jeep_Embedded_Controls_Main-B_Mask.gbr, Jeep_Embedded_Controls_Main-B_Paste.gbr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]
2026-05-29 Update README - PCBs ordered, full project documentation
    [Jeep_Embedded_Controls_Main-B_Cu.gbr, Jeep_Embedded_Controls_Main-B_Mask.gbr, Jeep_Embedded_Controls_Main-B_Paste.gbr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]
2026-05-29 Add PCB 3D render images to README
2026-06-14 Update README for bare-chip battery-backed redesign
    - Main controller: ESP32-DevKit V1 -> bare ESP32-WROOM-32E + CP2102N
    - Keyfob: ESP32-C3 Super Mini -> bare ESP32-C3FH4X + Johanson antenna
    - New battery-backed power architecture (aux AGM + vehicle-sensing charge relay)
    - Added hidden bypass kill switch and deep-sleep parked operation
    - Removed 5x aux light control (run separately)
    - Updated power, firmware, and PCB sections
2026-06-14 Rework firmware for battery-backed redesign
    - Main controller: deep-sleep/light-sleep tiered power model
    - Energized-to-run kill relay, hood + shock sensor monitoring
    - Firmware charge control with hysteresis, battery monitoring
    - SIM7600 power sequencing + GPS/MQTT skeleton (creds via NVS)
    - Keyfob: deep-sleep wake-on-button, ESP-NOW one-shot send
    - Remove old dev-board firmware (button_handler, led_handler, light tasks)
    [config.h, gpio_handler.c, main.c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]
2026-06-14 Update README: real firmware architecture, boards ordered
2026-06-14 Working on updating schematics
    [BOM-Jeep_Embedded_KeyFob.csv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]
